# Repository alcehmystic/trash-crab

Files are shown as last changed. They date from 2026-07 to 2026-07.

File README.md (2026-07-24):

<p align="center">
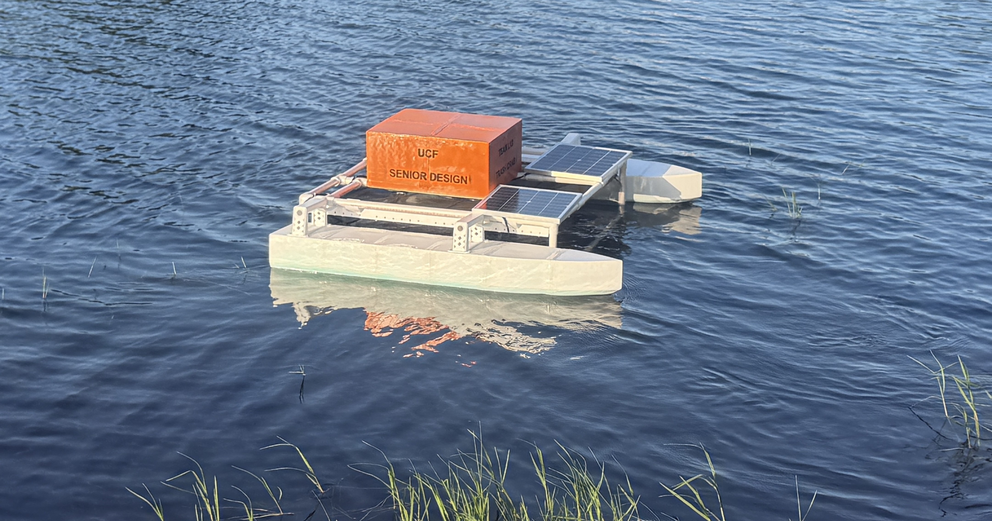
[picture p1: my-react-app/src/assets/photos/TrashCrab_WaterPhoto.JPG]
Trash Crab Team with Trash Crab Robot
  
</p>

<h1 align="center">The Trash Crab</h1>

<p align="center">
  An open-source, low-cost, tele-operated surface vehicle for collecting floating debris in lakes, ponds, and other calm freshwater bodies.
</p>

## About

Marine debris is a serious problem for wildlife, and there's no real affordable, mobile, wildlife-safe way to actively collect floating trash in small bodies of water. Shore crews can't reach open water, stationary filters only cover a fixed area, and pump-based systems risk harming aquatic life.

Trash Crab is our attempt at an answer: a solar-assisted, remote-controlled catamaran raft with a forward-facing mesh collection basket. An operator deploys the boat, drives it to intercept floating debris, and brings it back to empty the basket and recharge. The whole project (hardware, firmware, dashboard software, and 3D models) is published here so it can be built, used, and improved by others.

This project was built by Group L13 as a Computer Science Senior Design project at the University of Central Florida during the Spring/Summer 2026 semesters.

## Features

- **Remote tele-operation** over a long-range (~30 km) radio link, with WASD driving controls and a hardware-backed emergency stop
- **Live web dashboard** (React + MapLibre) showing GPS position and heading, connection status, and drive telemetry in real time
- **Automatic failsafe**: the boat stops itself if it loses contact with the operator
- **GPS tracking** with live position and heading shown on an interactive map
- **Onboard trash detection** using a fine-tuned YOLOv8n model running on a Luxonis OAK-D Lite stereo camera
- **Fully 3D-printed hull and basket**: STL/3MF files included for anyone who wants to build their own
- Designed around a bill of materials of roughly **$1,000-$1,300**, aiming to keep replication relatively affordable

## How it works

```
          Laptop (operator)                        Raspberry Pi 5 (onboard)
 +----------------------------------+   radio   +---------------------------+
 | React dashboard (Vite)           | <-------> | pi-side_telecom_server.py |
 |         |                        |  (LoRa)   |         |                 |
 |         v                        |           |         v                 |
 | dashboard-side_telecom_server.py |           | Arduino Nano (motors)     |
 |      (Flask)                     |           | VK-162 GPS (USB)          |
 |         |                        |           | OAK-D Lite (CV, planned)  |
 |         v                        |           +---------------------------+
 | COM port / radio dongle          |
 +----------------------------------+
```

- The dashboard sends drive commands (`W`/`A`/`S`/`D`) and an emergency stop to a small Flask server running locally on the operator's laptop, which forwards them over the radio link.
- The Raspberry Pi on the boat receives those commands, converts them into left/right motor speeds, and passes them to an Arduino Nano over serial, which handles the actual motor PWM.
- The Pi also reads GPS fixes from a USB GPS dongle and sends a telemetry packet back over the radio once a second (position, elapsed time, connection status, sensor placeholders).
- If the Pi stops receiving commands for more than a second, it cuts the motors on its own rather than waiting for another STOP command.

## Repository structure

```
trash-crab/
├── my-react-app/                       # Dashboard: React frontend + Flask telecom bridge
│   ├── src/                            # Dashboard UI (controls, live stats, map view)
│   ├── dashboard-side_telecom_server.py
│   └── requirements.txt
├── trash-crab-pi/                      # Code that runs on the Raspberry Pi
│   ├── pi-side_telecom_server.py
│   ├── arduino-motor-controller.ino    # Flashed onto the Arduino Nano
│   ├── startup-crab.service            # systemd unit for launching on boot
│   └── requirements.txt
├── assembly/                           # Build guide and reference photos
│   ├── ASSEMBLY.md
│   └── photos/
└── stl-files/                          # 3D-printable hull, basket, and mount parts
```

## Hardware overview

| Vessel | Catamaran-style raft, ~36" L x 48" W x 20" H, forward mesh collection basket |
|---|---|
| Capacity | ~70 gallon basket volume |
| Speed / Range | 0.5–1 m/s / up to ~30 km on the radio link |
| Runtime | 4–6 hours per charge, extended by onboard solar panels (~12–15 hrs to recharge) |

| Layer | Hardware |
|---|---|
| Main computer | Raspberry Pi 5 (Python, headless) |
| Low-level motor control | Arduino Nano running [`arduino-motor-controller.ino`](trash-crab-pi/arduino-motor-controller.ino) (C++, PWM over serial) |
| Navigation | VK-162 USB GPS module |
| Radio link | LoRa LR900-F data transmit module |
| Vision | Luxonis OAK-D Lite (stereo camera + onboard NPU) |

3D-printable parts for the hulls, collection basket, thruster mounts, and component enclosure are in [`stl-files/`](stl-files/). Step-by-step build instructions with photos are in the [assembly manual](assembly/ASSEMBLY.md).

## Machine learning

Floating debris detection runs on a YOLOv8n model, fine-tuned on the FloW-A dataset (floating waste in inland waterways, ICCV 2021) using the Ultralytics training framework. It reached an mAP@0.5 of 0.873 with an 84% true positive detection rate on validation data, and is small enough to run in real time on the OAK-D Lite's onboard NPU. Obstacle detection and a basket-fullness estimator (OpenCV frame analysis) were designed alongside it; obstacle detection is still waiting on a training dataset before it can ship.

## Getting started

You'll need two things running: the code on the Raspberry Pi (boat side) and the dashboard on your laptop (operator side). They talk to each other over a matched pair of radio modules: one plugged into the Pi, one plugged into the laptop.

### Prerequisites

- Raspberry Pi 5 with Python 3.9+, wired to an Arduino Nano, a VK-162 GPS dongle, and a radio module
- The Arduino Nano flashed with [`arduino-motor-controller.ino`](trash-crab-pi/arduino-motor-controller.ino) (steps below, right from the Pi's terminal)
- A laptop with [Node.js](https://nodejs.org/) 18+ and Python 3.9+, with a matching radio module plugged in
- Both Python environments need their own virtual environment (recommended) and dependencies from the matching `requirements.txt`
- [Git](https://git-scm.com/) 2.25+ on both machines, to clone just the folder each one needs

### 1. Raspberry Pi setup

```bash
mkdir trash-crab && cd trash-crab
git clone --filter=blob:none --sparse https://github.com/alcehmystic/trash-crab.git .
git sparse-checkout set trash-crab-pi
cd trash-crab-pi
python -m venv .venv
source .venv/bin/activate
pip install -r requirements.txt
```

#### Flashing the Arduino Nano

This uses [arduino-cli](https://arduino.github.io/arduino-cli/), so the Nano can be flashed straight from the Pi's terminal with the Nano plugged in over USB, no separate desktop or GUI IDE needed. Install it once, along with the AVR core and the `Servo` library the sketch needs:

```bash
curl -fsSL https://raw.githubusercontent.com/arduino/arduino-cli/master/install.sh | sh
sudo mv bin/arduino-cli /usr/local/bin/
arduino-cli core update-index
arduino-cli core install arduino:avr
arduino-cli lib install Servo
```

Arduino sketches must live in a folder with the same name as the `.ino` file, so copy it into one, then compile and upload:

```bash
mkdir arduino-motor-controller
cp arduino-motor-controller.ino arduino-motor-controller/
arduino-cli compile --fqbn arduino:avr:nano arduino-motor-controller
arduino-cli upload -p /dev/ttyUSB0 --fqbn arduino:avr:nano arduino-motor-controller
```

Run `arduino-cli board list` first if you're not sure which port the Nano shows up as. This only needs to be redone if `arduino-motor-controller.ino` changes.

Before running `pi-side_telecom_server.py`, open it and check the **CONFIGURATION** block near the top of the file. It lists the serial ports for the radio, the Arduino, and the GPS dongle. The defaults match our own Pi, but yours will likely enumerate differently. Run `ls -l /dev/serial/by-id/` on the Pi to find the correct by-id names for your own devices and swap them in.

```bash
python pi-side_telecom_server.py
```

#### Starting automatically on boot

[`startup-crab.service`](trash-crab-pi/startup-crab.service) is a systemd unit that launches `pi-side_telecom_server.py` on boot, so the boat is ready to drive as soon as the Pi powers on, with no monitor, keyboard, or WiFi needed. Edit the `WorkingDirectory` and `ExecStart` paths inside it to match where you cloned the repo on your own Pi, then install it:

```bash
sudo cp startup-crab.service /etc/systemd/system/
sudo systemctl daemon-reload
sudo systemctl enable --now startup-crab.service
```

Check on it with `systemctl status startup-crab.service`, or watch its logs live with `journalctl -u startup-crab.service -f`.

### 2. Dashboard setup

```bash
mkdir trash-crab && cd trash-crab
git clone --filter=blob:none --sparse https://github.com/alcehmystic/trash-crab.git .
git sparse-checkout set my-react-app
cd my-react-app
npm install
python -m venv .venv
source .venv/bin/activate
pip install -r requirements.txt
```

Open `dashboard-side_telecom_server.py` and set `PORT` (near the top of the file) to whatever COM port your radio adapter shows up as (Device Manager on Windows, or `/dev/tty*` on Mac/Linux).

```bash
npm run dev
```

This starts the Vite dev server and the telecom bridge together. The program is ran entirely offline. Open `http://localhost:5173` in a browser to see the dashboard. If you'd rather run them separately, use `npm run dev:frontend` and `npm run dev:telecom` in two terminals.

### Getting the whole repository

The steps above only pull down the one folder each device needs. If you want everything at once instead, including the [`stl-files/`](stl-files/) for 3D printing your own parts, just do a normal full clone:

```bash
git clone https://github.com/alcehmystic/trash-crab.git
cd trash-crab
```

## Bill of materials

Rough parts list and cost for building your own Trash Crab. Prices are estimates and will shift depending on suppliers and substitutions. Some parts are noted with a brand due to components being sized around them.

| Category | Component(s) |
|---|---|
| Compute / Control | Raspberry Pi 5 (8GB) x1, Arduino Nano x1 |
| Sensors & Navigation | VK-162 GPS (w/ or w/o magnetometer) x1, MPU6050 IMU x3, leak sensor x4 |
| Propulsion | 12V brushless underwater thrusters w/ESC x4 (We used DIAMONDDYNAMICS 1.2kg Thrust model) |
| Structure & Hull | PETG filament (~9-10kg, depending on print settings), 3/4" PVC pipe for the frame (40-45 ft, cut to length), PVC fittings (3-piece corner-connectors x8, 3-piece T-connectors x12, 4-piece cross-connectors x4) |
| Waterproofing/Glue | Marine silicone sealant 10oz x2 (for hulls, frame, and box) |
| Power System | 12.8V 100Ah LiFePO4 battery x1 (DEASON), 20W solar panel w/charge hub x2 (SOLPERK), power distribution board x1, 12v to 5v/5A Buck Converter to USB-C x1, wiring and adapters |
| Communications | MicoAir LoRa LR900-F radio data transmit module x1 |
| Connections | 1/2" #10-32 non-countersunk bolts/nuts x16 |

**Estimated total: $900-$1,200**, depending on part pricing and substitutions.

## Team

| Name | Role |
|---|---|
| Benedetto Falin | Hardware Construction / SCRUM Manager |
| Kevin Fernandez | Hardware Construction |
| Robert Botorog | Machine Learning / Computer Vision |
| Kameron Hyles | Machine Learning / Computer Vision |
| Hailey Kristona | Software / GUI |
| Phuong Trinh Le | Software / GUI |

## License

This project is licensed under the [MIT License](LICENSE).

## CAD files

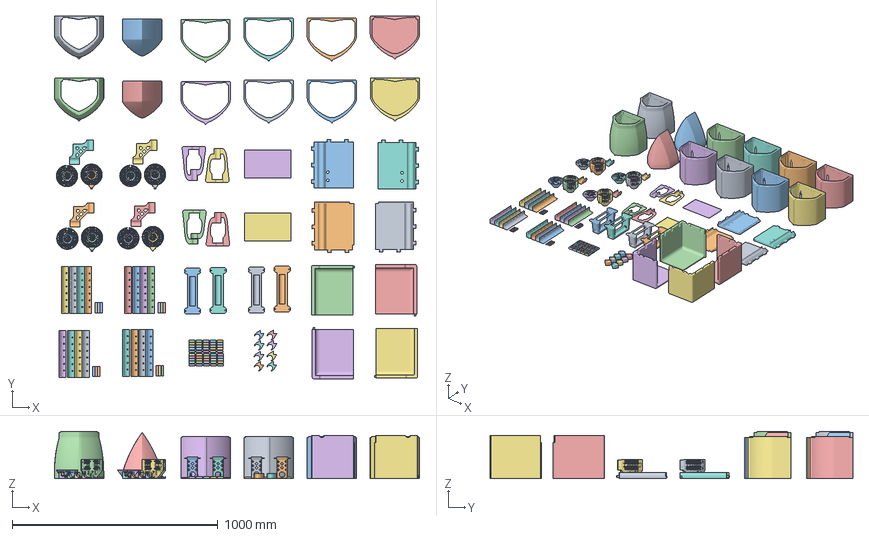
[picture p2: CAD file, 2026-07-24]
stl-files/Catamaran Modules/Catamaran Module - Bow.3mf
1777.6 x 1766.1 x 230.0 mm
Back Bow Body x 2
Front Bow Body x 2
Battery Plate - left
Battery Plate - right
Plate (Left) (1)
Plate (Right)
Plate (Left)
Plate (Right) (1)
Connection Grip x 4
Front Cone x 4
Mid-Body & Back Cone x 4
Clip x 8
Dowel Pin x 12
Length Piece (1) x 4
Length Piece x 12
Cover (1) (1)
Cover (2)
Cover (1)
Cover

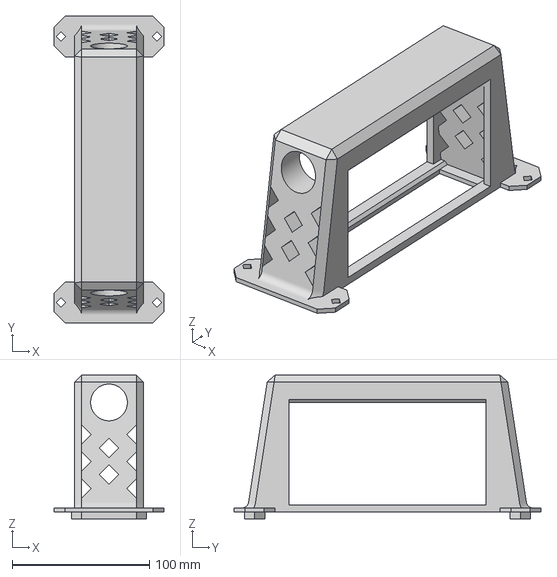
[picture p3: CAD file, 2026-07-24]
stl-files/Handle Grip.3mf
80.0 x 224.0 x 105.0 mm

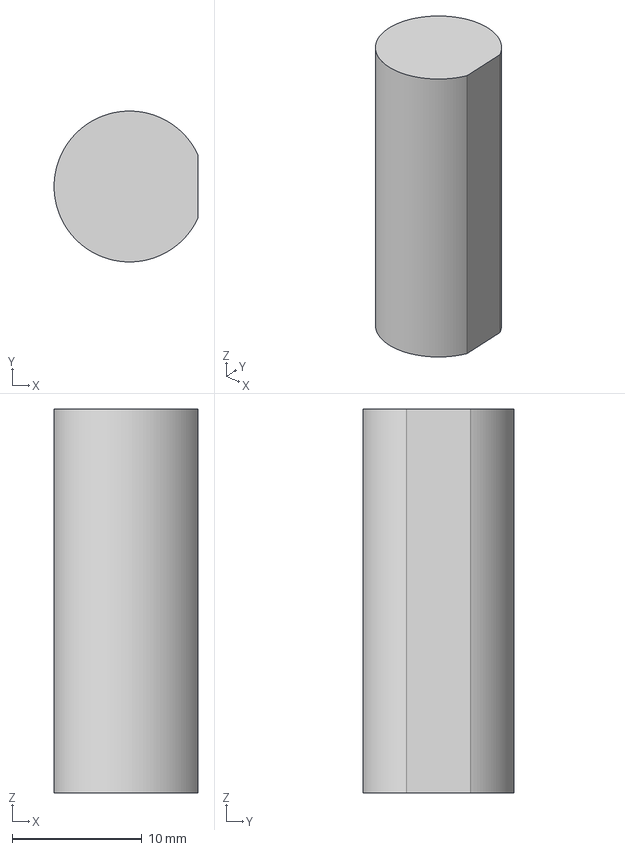
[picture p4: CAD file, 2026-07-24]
stl-files/Catamaran Modules/D-shaft pin.3mf
11.1 x 11.6 x 29.6 mm

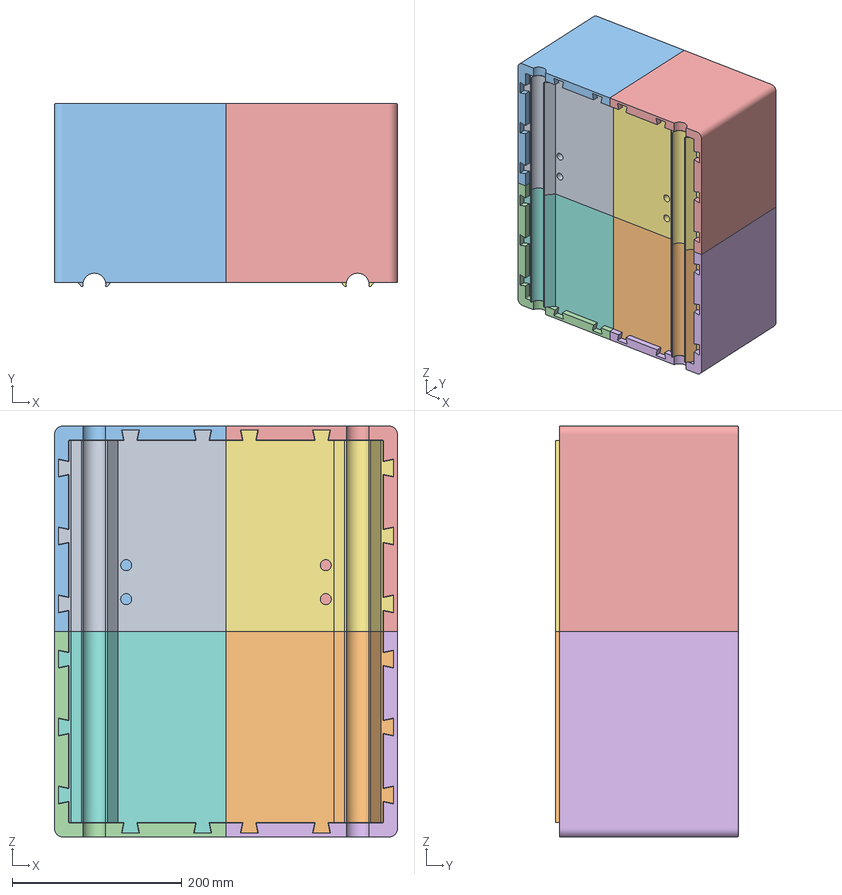
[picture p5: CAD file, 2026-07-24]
stl-files/Components Box & Plate.3mf
404.0 x 215.8 x 484.0 mm
Battery Plate - left
Battery Plate - right
Cover (1) (1)
Cover (1)
Cover (2)
Cover
Plate (Left) (1)
Plate (Left)
Plate (Right) (1)
Plate (Right)

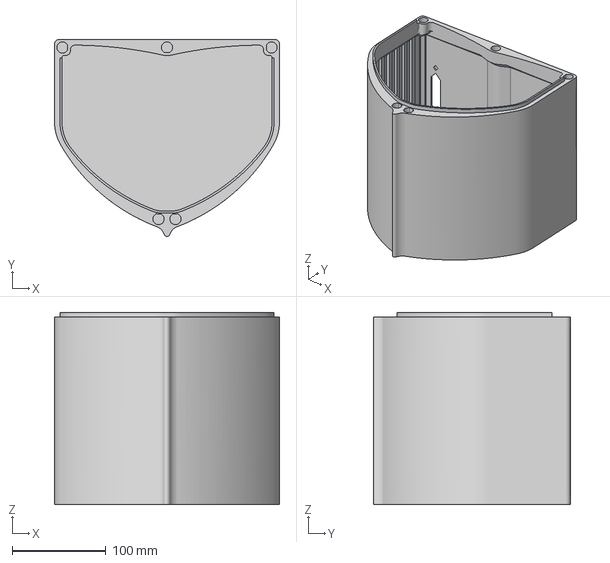
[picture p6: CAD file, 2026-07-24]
stl-files/Catamaran Modules/Catamaran Module - Back.3mf
240.0 x 210.1 x 205.0 mm

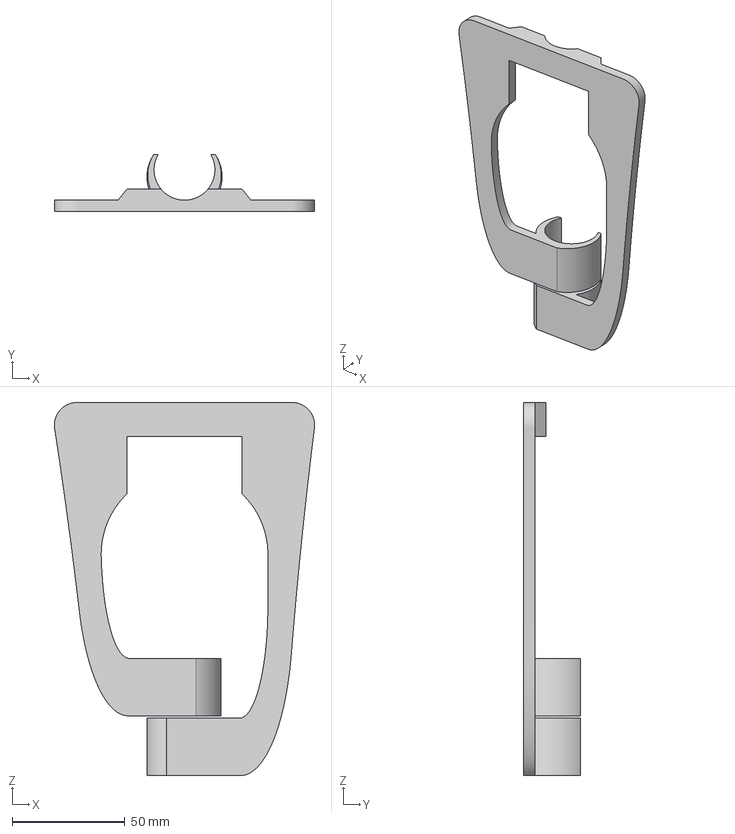
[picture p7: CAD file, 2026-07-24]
stl-files/Hull Grip.3mf
115.2 x 25.2 x 165.1 mm

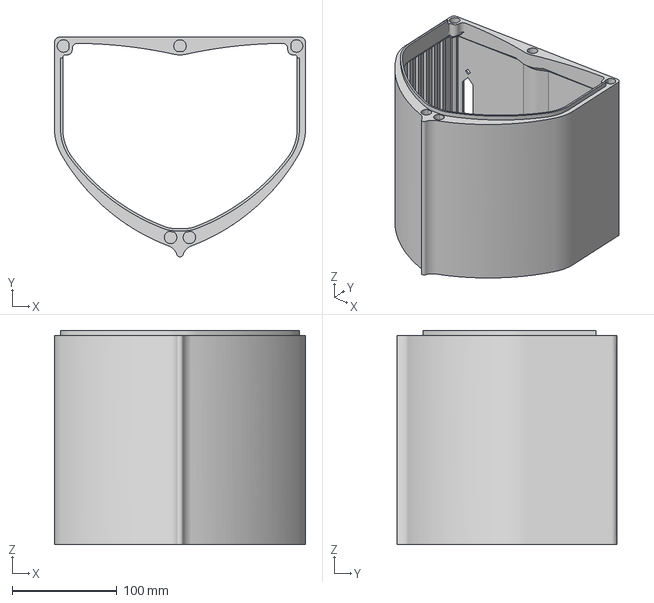
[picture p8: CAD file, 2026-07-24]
stl-files/Catamaran Modules/Catamaran Module - Middle.3mf
240.0 x 210.1 x 205.0 mm

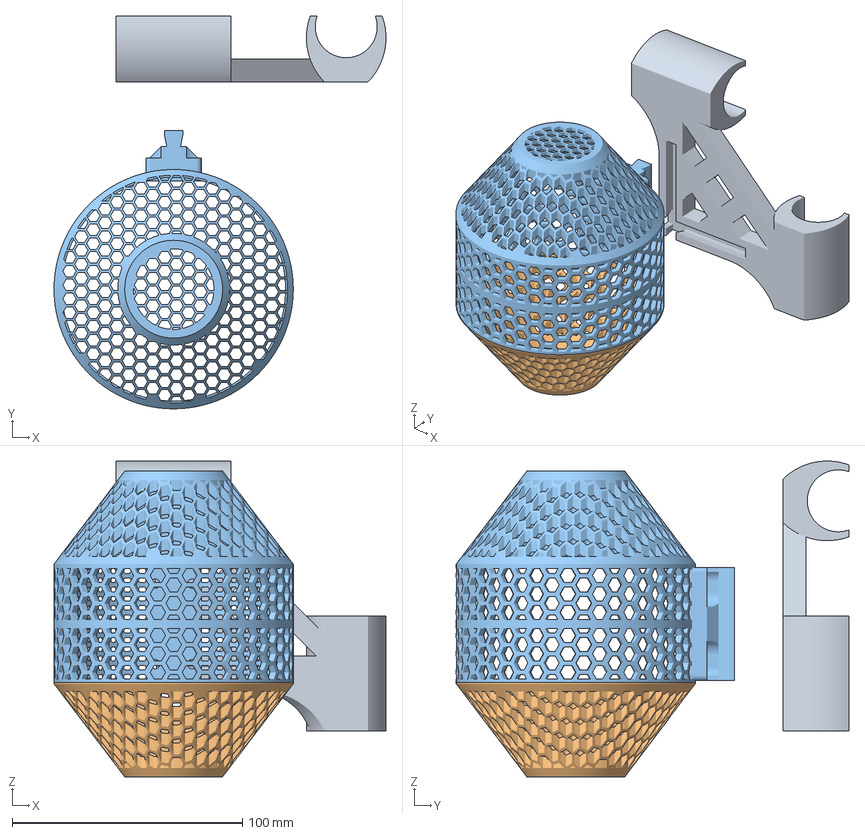
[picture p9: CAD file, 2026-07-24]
stl-files/Thuster Guard & Mount.3mf
144.3 x 170.6 x 137.3 mm
Connection Grip
Front Cone
Mid-Body & Back Cone

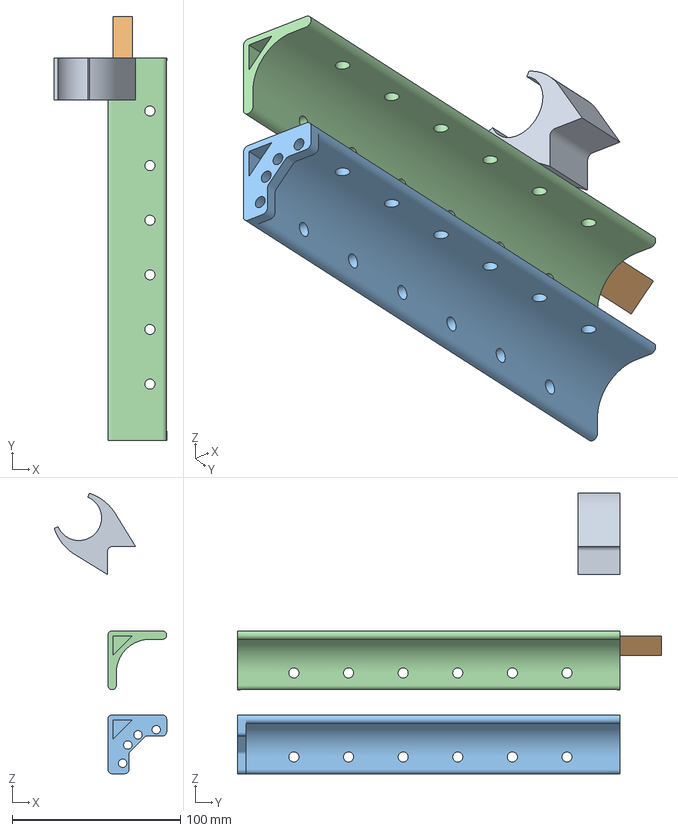
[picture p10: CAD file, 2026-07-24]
stl-files/Basket Structure.3mf
66.9 x 252.3 x 166.9 mm
Clip
Dowel Pin
Length Piece (1)
Length Piece

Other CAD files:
stl-files/Trash Crab 3D Printed Parts 3MF.3mf

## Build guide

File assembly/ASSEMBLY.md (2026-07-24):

# Trash Crab Assembly Manual

This is the build guide for the Trash Crab's hull, frame, basket, and components box. It covers physical assembly only. For flashing the Arduino and running the software, see the [main README](../README.md).

Before starting, print all the parts listed in [`stl-files/`](../stl-files/) and gather the materials in the [Bill of materials](../README.md#bill-of-materials).

The build goes in six stages, roughly in the order you'll actually want to do them:

1. [Assemble the hulls](#1-assemble-the-hulls)
2. [Cut and assemble the PVC frame](#2-cut-and-assemble-the-pvc-frame)
3. [Mount the hulls to the frame](#3-mount-the-hulls-to-the-frame)
4. [Build and mount the basket rails](#4-build-and-mount-the-basket-rails)
5. [Cut and fold the basket netting](#5-cut-and-fold-the-basket-netting)
6. [Assemble the components box and finish](#6-assemble-the-components-box-and-finish)

## 1. Assemble the hulls

Each hull is printed as six segments (bow, four middle modules, stern) that key together with alignment pins before being joined permanently. You'll build two identical hulls.

Lay the six segments out in order and dry-fit them so the alignment pins line up before committing to glue or sealant.

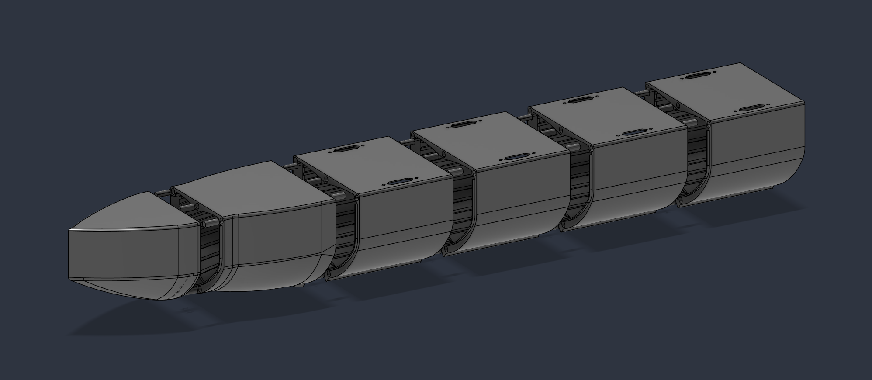
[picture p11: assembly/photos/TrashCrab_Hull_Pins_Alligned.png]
Hull segments laid out in order, pins aligned


Each hull gets two carry grips, attached via four 1/2" #10x32 non-countersunk bolts. These should be hand tightened and not overdone. These must be added before gluing, as there is no way to access the nut after the hulls are sealed.

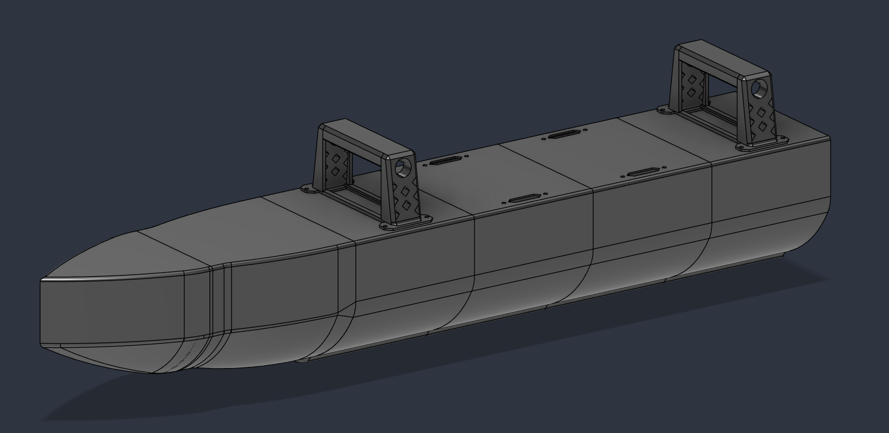
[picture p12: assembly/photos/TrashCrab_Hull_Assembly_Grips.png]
Completed hull with both grips mounted


Apply marine silicone adhesive sealant to each seam, as well as a small dollop on the dowel-pin's hole, and join the segments end to end. This is best done by stacking the hull pieces vertically, with the back catamaran module on the floor, pressing down firmly so sealant seeps out along the edges. Apply a ream of silicone sealant along this outer seam and smooth with a brush or finger (gloved) to create a cleaner seal.

The extra top holes for additional/optional handles can be sealed as well if they are not desired.

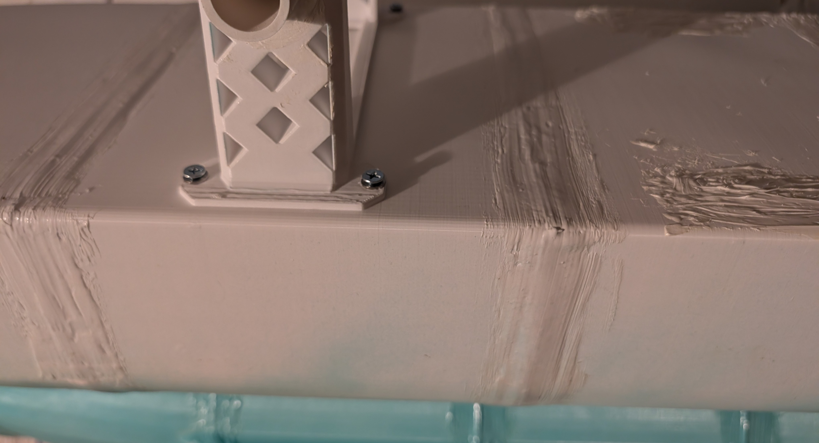
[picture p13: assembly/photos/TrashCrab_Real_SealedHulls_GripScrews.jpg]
Sealed hulls with grip screws installed


Repeat this whole stage for the second hull.

## 2. Cut and assemble the PVC frame

The frame is made from 3/4" Schedule 40 PVC, cut to the lengths below and joined with standard PVC 3-piece corner and T connectors.

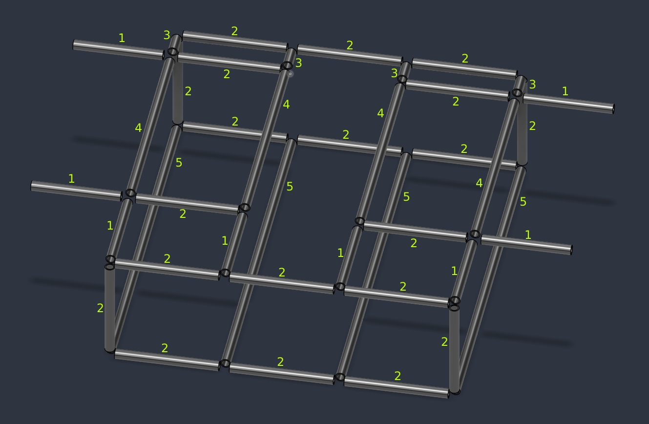
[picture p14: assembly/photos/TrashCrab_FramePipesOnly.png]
PVC frame with each pipe length numbered


Cut list (numbers correspond to the labels above; double check against the diagram before cutting):

| Length | Count | Label |
|---|---|---|
| 9.5" | x8 | (1) |
| 11" | x20 | (2) |
| 2.25" | x4 | (3) |
| 22" | x4 | (4) |
| 37" | x4 | (5) |

**Total: ~45 ft of pipe in total.**

Dry-fit the whole frame with the 3-piece corner and T connectors before gluing anything, to confirm square and fit. We used the same marine silicone adhesive sealant to glue the frame, but any water-safe and flexible PVC glue should work fine.

## 3. Mount the hulls to the frame

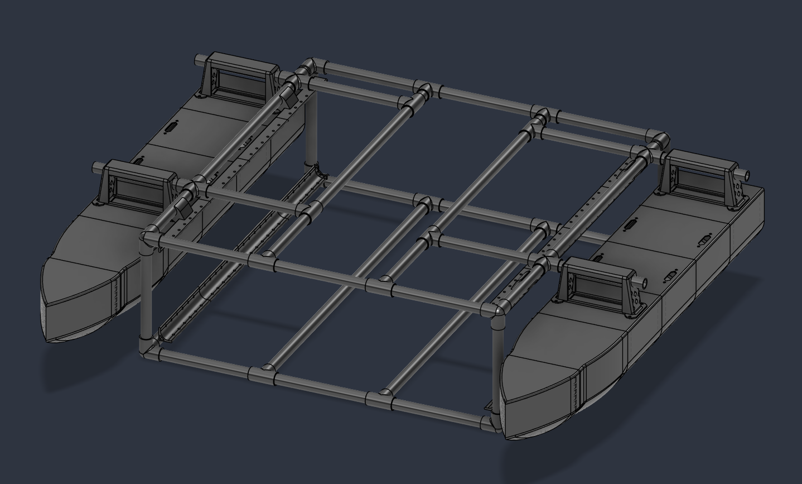
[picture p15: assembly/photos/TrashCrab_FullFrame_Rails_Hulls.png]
Full frame with both hulls and basket rails attached


Each hull gets two of the 9.5" PVC pieces from the frame through the handle grips. This will be a tight fit depending on your printer's tolerances, so be careful not to crack the handles. The pipes should stick out (in the direction of the hull's mounting side) no less than 1" from the handle. Any less, and it risks not fully seating into the frame's cross connection. Aim for 1" - 1.5" so the hull can rest against the frame without sagging. Mirror this direction on the opposite hull as seen above.

Once tested for proper fitting, some glue can be used to lock the PVC pipe to the hull handle grip. Do not seal the PVC pipe to the frame connection, unless you do not want them to be removable.

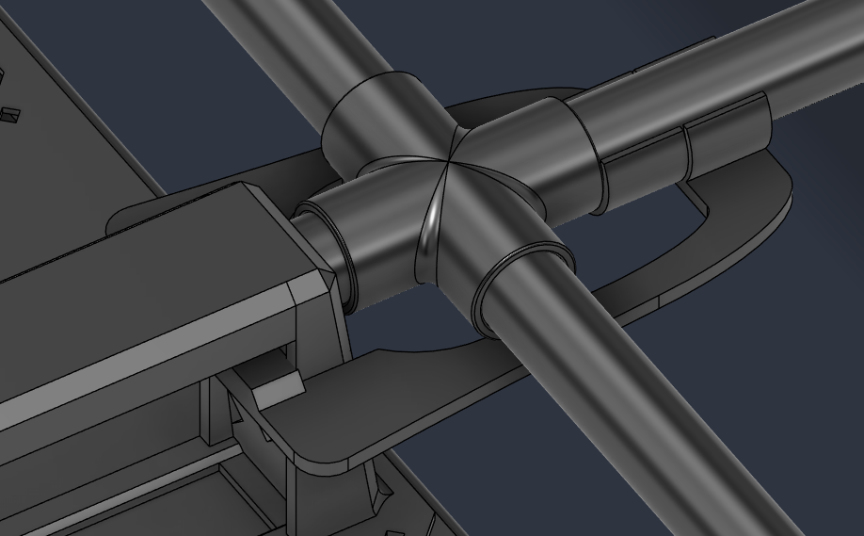
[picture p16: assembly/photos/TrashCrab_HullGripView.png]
Close-up of a hull grip attachment point


Each hull also gets one hull grip clamp. These are bent and placed around the inside of the handle grips, clipping onto the inside PVC frame to ensure the hulls do not slip out of their connection during usage. Before any significant stress is placed on the hulls, the hull grip clamps should be placed and verified for strength.

## 4. Build and mount the basket rails

The basket rails run along the inside of the frame and hold the netting via zip-ties through the provided holes.

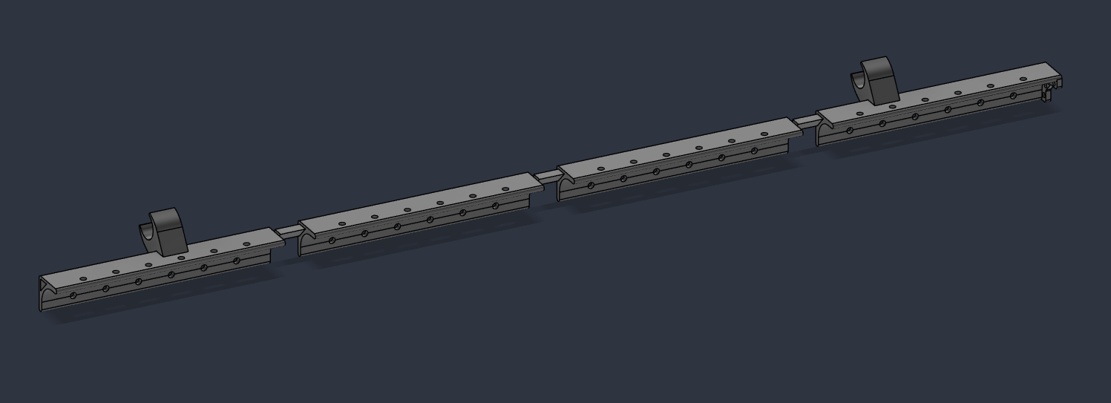
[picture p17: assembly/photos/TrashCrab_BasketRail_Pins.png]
Basket rail segments joined end to end with pin connectors


Join the four rail segments with the triangle-pin connectors with a ream of the marine silicone adhesive sealant on their joining faces to ensure they do not come apart. Note the C-clip hook at each end, used later to hold the netting.

Rail clip hole spacing

Line the C-clips up to be 5" (127mm used as rough guide) from either end of the rail. Apply a ream of the marine silicone adhesive sealant on the inside of each joining face of the C-clip. Press together firmly and let dry.

## 5. Cut and fold the basket netting

We made our basket from garden/plant-safe netting, cut from a flat pattern and folded into shape. Other materials can be used, but remember this will be mainly used for trash collection with constant water flow.

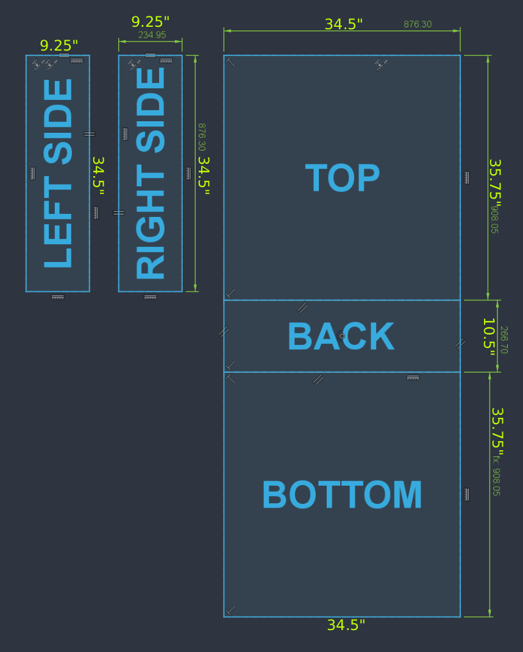
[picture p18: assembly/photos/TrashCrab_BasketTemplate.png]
Flat cutting template: top, back, left side, right side, bottom


Cut the netting to this pattern with the given dimensions in the image above. The dimensions are also listed below:

| Face | Length (vertical) | Width (horizontal) |
|---|---|---|
| Top/Bottom | 35.75" | 34.5" |
| Back | 10.5" | 34.5" |
| Left/Right Side | 34.5" | 9.25" |

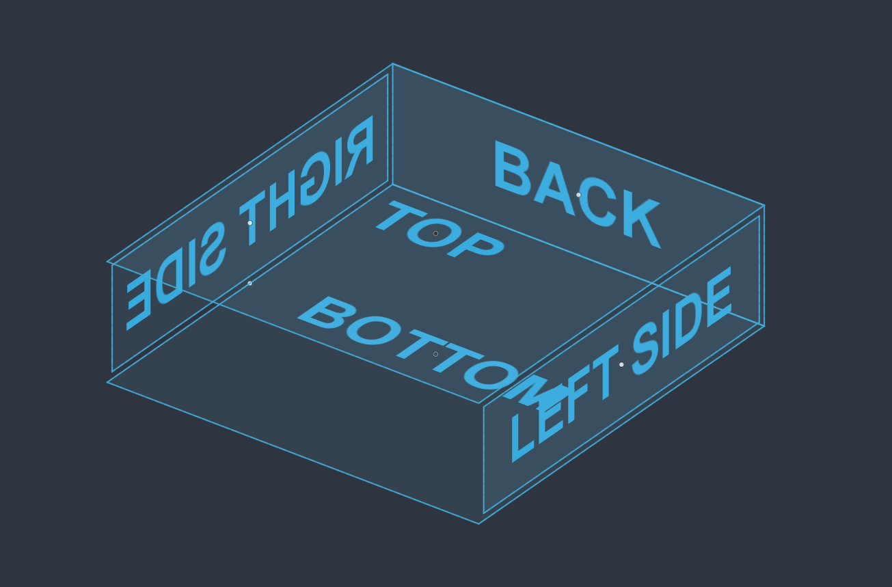
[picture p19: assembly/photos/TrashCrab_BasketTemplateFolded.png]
Template folded into the basket shape


Fold along the seams shown above into the basket shape. The sides are not attached via the folds and are solely zip-tied to the rails.

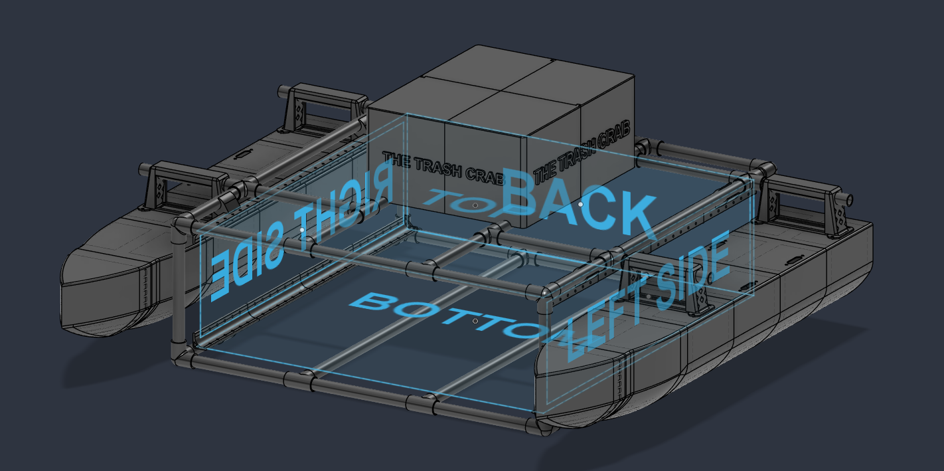
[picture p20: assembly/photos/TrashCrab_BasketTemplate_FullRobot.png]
Basket shown in place on the frame


Attach the folded basket to the rail clips with zip-ties, positioned as shown.

## 6. Assemble the components box and finish

The components box holds the electronics and splits into a lid and base.

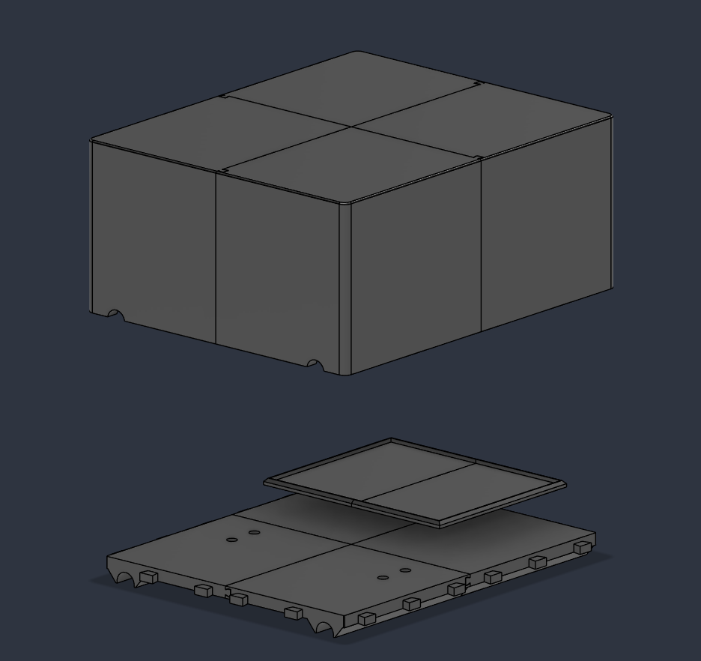
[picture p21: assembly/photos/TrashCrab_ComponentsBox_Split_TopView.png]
Components box, lid and base split, top view


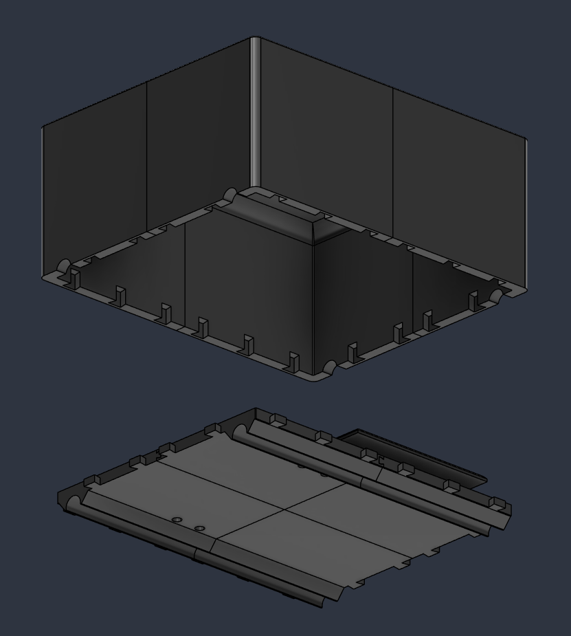
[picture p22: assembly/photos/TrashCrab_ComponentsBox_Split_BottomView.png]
Components box, lid and base split, bottom view


The plates and lid pieces each connect into their respective components via dovetail notches. Each female-side dovetail notch should be lined with some marine silicone adhesive sealant before attaching the pieces.

The plate starts as four pieces which attach in pairs of two, along the short-side dovetail notch to create the left/right sides. These then attach together along the long-side dovetail notch. 

The lid attaches in a spiral fashion with each dovetail notch locking the sides together.

Once all pieces of each component are sealed together, it is recommended to add a ream along the outer seams, similar to what was done when initially sealing the hulls, to ensure a strong connection.

Wire up the electronics inside the base before closing the lid. It slots right onto the plate and sinks down onto it via the dovetail slots on its outer edge. See the main README for the Pi/Arduino/GPS wiring.

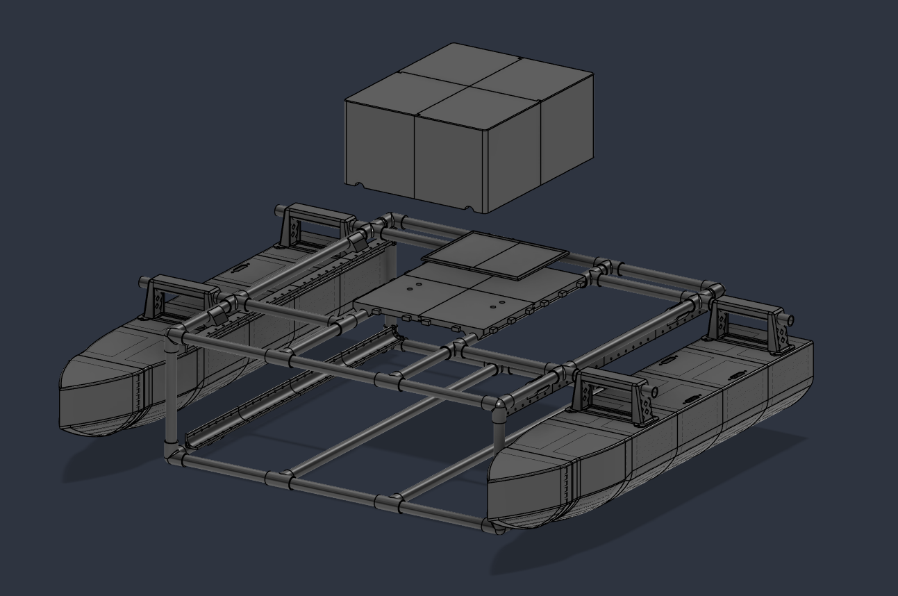
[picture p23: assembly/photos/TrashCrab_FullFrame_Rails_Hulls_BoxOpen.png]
Frame with hulls and rails, box lifted off to show mounting


Mount the box to the frame at the back-middle of the bot with the main battery plate closest to the center for weight distribution. The plate attaches onto the inner PVC pipes running down the center of the top portion of the frame via its C-clips along its bottom.

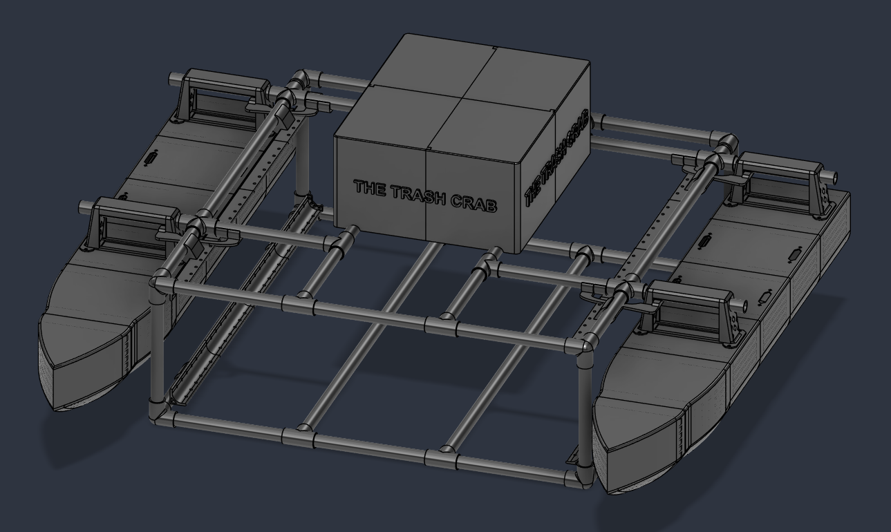
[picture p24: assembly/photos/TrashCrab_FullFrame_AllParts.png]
Fully assembled Trash Crab with box closed


With the box closed, the build is complete. Continue with the [Getting started](../README.md#getting-started) section of the main README to flash the Arduino and bring the electronics online.

Congrats on creating your very own Trash Crab, and thank you for the faith you have placed in this guide as you do so.

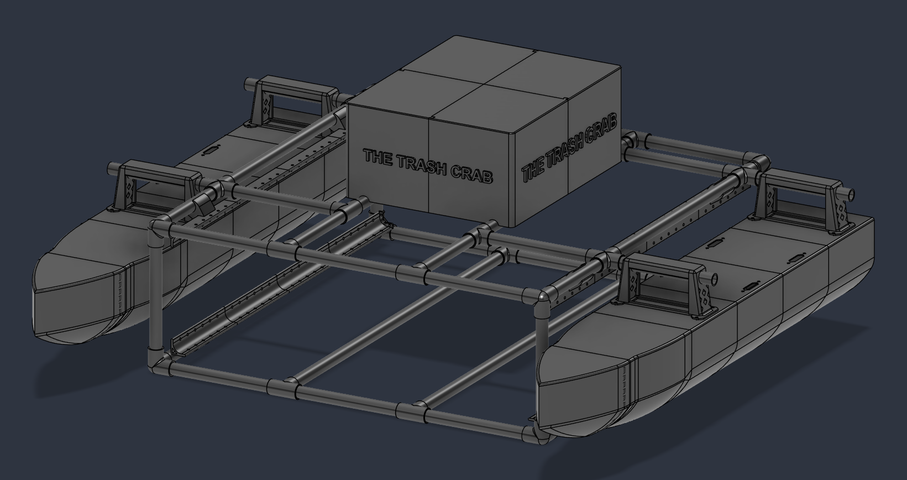
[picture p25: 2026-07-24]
assembly/photos/TrashCrab_FullFrame_Rails_Hulls_BoxClosed.png

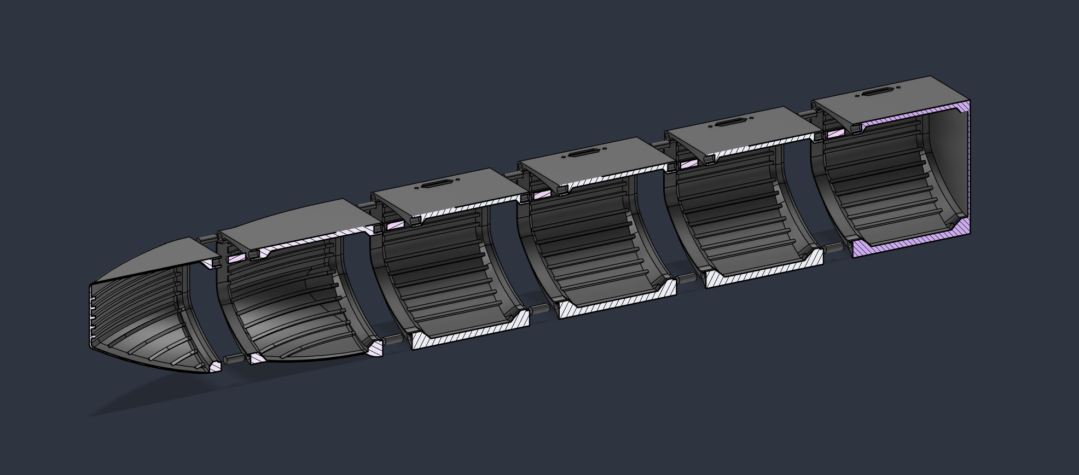
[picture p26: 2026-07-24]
assembly/photos/TrashCrab_Hull_Pins_Alligned_Cut.png

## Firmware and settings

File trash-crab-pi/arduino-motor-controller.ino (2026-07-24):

/*
  arduino-motor-controller.ino

  Runs on the Arduino Nano, connected to the Raspberry Pi over USB serial.
  Owns all real-time motor control: PWM generation, ESC arming, and smooth
  speed ramping. The Pi only sends high-level target speeds; this sketch
  is responsible for actually reaching them safely.

  Motor layout (tank/differential drive, 2 pairs):
    LEFT  pair = PIN_LEFT_FRONT, PIN_LEFT_REAR
    RIGHT pair = PIN_RIGHT_FRONT, PIN_RIGHT_REAR

  Serial protocol (from the Pi, one command per line, newline terminated):
    ARM              -> re-run the ESC arming sequence (neutral hold)
    STOP             -> immediate hard cut to neutral, bypasses the ramp
    T:<left>,<right> -> set target speed for each side, -100..100 (percent)

  PWM convention (ESC standard, in microseconds):
    1500us = neutral / stopped
    2000us = full forward
    1000us = full reverse
  MAX_SPEED_PCT caps how far from neutral we will ever command, no matter
  what target is requested.
*/

#include <Servo.h>

// =====================================================================
// CONFIGURATION - update the pin numbers below if your ESCs are wired
// to different pins. Defaults shown are what our Trash Crab unit uses.
// =====================================================================
const uint8_t PIN_LEFT_FRONT  = 3;
const uint8_t PIN_LEFT_REAR   = 5;
const uint8_t PIN_RIGHT_FRONT = 6;
const uint8_t PIN_RIGHT_REAR  = 9;

const int PULSE_NEUTRAL      = 1500;
const int PULSE_FORWARD_MAX  = 2000;
const int PULSE_REVERSE_MAX  = 1000;
const float MAX_SPEED_PCT    = 85.0;   // hard safety cap, mirrors the Pi-side cap
const unsigned long RAMP_MS  = 1500;   // time to sweep the full -100..100 range

Servo escLF, escLR, escRF, escRR;

// Current and target speeds, in percent (-100..100, later clamped to MAX_SPEED_PCT).
float currentLeft = 0, currentRight = 0;
float targetLeft  = 0, targetRight = 0;
unsigned long lastUpdate = 0;

String inputBuffer = "";

// Converts a -100..100 percent value into a microsecond pulse and writes it.
void writeMotor(Servo &esc, float percent) {
  percent = constrain(percent, -MAX_SPEED_PCT, MAX_SPEED_PCT);
  int pulse;
  if (percent >= 0) {
    pulse = PULSE_NEUTRAL + (percent / 100.0) * (PULSE_FORWARD_MAX - PULSE_NEUTRAL);
  } else {
    pulse = PULSE_NEUTRAL + (percent / 100.0) * (PULSE_NEUTRAL - PULSE_REVERSE_MAX);
  }
  esc.writeMicroseconds(pulse);
}

// ESCs need a neutral signal held for a few seconds before they'll accept
// throttle commands. Runs at boot and again any time "ARM" is received.
void armEscs() {
  Serial.println("Arming ESCs (neutral hold)...");
  escLF.writeMicroseconds(PULSE_NEUTRAL);
  escLR.writeMicroseconds(PULSE_NEUTRAL);
  escRF.writeMicroseconds(PULSE_NEUTRAL);
  escRR.writeMicroseconds(PULSE_NEUTRAL);
  delay(3000);
  currentLeft = currentRight = 0;
  targetLeft  = targetRight  = 0;
  Serial.println("Armed.");
}

void setup() {
  Serial.begin(57600);
  escLF.attach(PIN_LEFT_FRONT);
  escLR.attach(PIN_LEFT_REAR);
  escRF.attach(PIN_RIGHT_FRONT);
  escRR.attach(PIN_RIGHT_REAR);

  armEscs();
  lastUpdate = millis();
}

// Moves currentLeft/currentRight toward their targets at a fixed rate, so a
// full -85..85 sweep takes about RAMP_MS. Non-blocking, called every loop() tick.
void applyRamp() {
  unsigned long now = millis();
  unsigned long dt = now - lastUpdate;
  lastUpdate = now;

  float maxStep = (2.0 * MAX_SPEED_PCT) * (float)dt / (float)RAMP_MS;

  if (currentLeft < targetLeft)       currentLeft = min(currentLeft + maxStep, targetLeft);
  else if (currentLeft > targetLeft)  currentLeft = max(currentLeft - maxStep, targetLeft);

  if (currentRight < targetRight)      currentRight = min(currentRight + maxStep, targetRight);
  else if (currentRight > targetRight) currentRight = max(currentRight - maxStep, targetRight);

  writeMotor(escLF, currentLeft);
  writeMotor(escLR, currentLeft);
  writeMotor(escRF, currentRight);
  writeMotor(escRR, currentRight);
}

void handleCommand(String cmd) {
  cmd.trim();
  if (cmd.length() == 0) return;

  if (cmd == "STOP") {
    // Emergency stop: cut immediately, do not ramp down.
    targetLeft = 0;
    targetRight = 0;
    currentLeft = 0;
    currentRight = 0;
  } else if (cmd == "ARM") {
    armEscs();
  } else if (cmd.startsWith("T:")) {
    int commaIdx = cmd.indexOf(',');
    if (commaIdx > 2) {
      float l = cmd.substring(2, commaIdx).toFloat();
      float r = cmd.substring(commaIdx + 1).toFloat();
      targetLeft  = constrain(l, -MAX_SPEED_PCT, MAX_SPEED_PCT);
      targetRight = constrain(r, -MAX_SPEED_PCT, MAX_SPEED_PCT);
    }
  }
}

// Called automatically by the Arduino core after each loop() pass whenever
// serial data is available. Standard on the Uno/Nano.
void serialEvent() {
  while (Serial.available()) {
    char c = Serial.read();
    if (c == '\n') {
      handleCommand(inputBuffer);
      inputBuffer = "";
    } else if (c != '\r') {
      inputBuffer += c;
    }
  }
}

void loop() {
  applyRamp();
  delay(20); // ~50Hz control loop
}

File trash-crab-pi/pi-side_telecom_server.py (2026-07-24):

"""
pi-side_telecom_server.py

Runs on the Raspberry Pi. This is the bridge between the long-range radio
link (to the dashboard laptop), the Arduino Nano motor controller (over
USB serial), and the VK-162 USB GPS dongle.

What it does:
  - Reads WASD control packets sent from the laptop over radio
  - Converts them into left/right motor speeds and forwards them to the
    Arduino as "T:<left>,<right>"
  - Runs a failsafe watchdog that stops the boat if no control packet
    arrives in time (radio dropout, laptop crash, etc.)
  - Reads NMEA sentences from the GPS dongle and includes the latest fix
    in telemetry
  - Sends a telemetry packet back to the laptop once a second

DEBUG MODE:
  If the Arduino can't be opened on ARDUINO_PORT, the script doesn't crash -
  it just prints what it would have sent instead of writing to serial. Set
  FORCE_DEBUG_MODE = True below to force this even with the Arduino plugged
  in (useful for testing control logic before the hardware is wired up).

Radio protocol from the laptop (newline terminated):
  "ARM"          -> arm the ESCs
  "STOP"         -> emergency stop
  "CTRL:<keys>"  -> currently held keys, e.g. "CTRL:wa" for forward+left

Radio messages sent back to the laptop (newline terminated):
  {"type":"telemetry", ...}  -> once per second
  "Pi: ..."                  -> plain-text ACKs for ARM/STOP/CTRL

GPS setup:
  Needs pynmea2 to parse NMEA sentences: pip install pynmea2
  If it's not installed, or the dongle isn't plugged in, the GPS thread
  just logs that once and disables itself - everything else keeps running.
"""

import serial
import sys
import threading
import time
import json

# Running under systemd buffers stdout in full blocks instead of by line,
# so prints don't show up in `journalctl` until the buffer fills. Force
# line buffering so log output shows up right away.
try:
    sys.stdout.reconfigure(line_buffering=True)
    sys.stderr.reconfigure(line_buffering=True)
except Exception:
    pass

# =====================================================================
# CONFIGURATION - update the port values below to match your own setup.
# Defaults shown are what our Trash Crab unit uses.
# =====================================================================

# Long-range radio link to the laptop dashboard.
RADIO_PORT = "/dev/serial/by-id/usb-Silicon_Labs_CP2102_USB_to_UART_Bridge_Controller_0001-if00-port0"
RADIO_BAUD = 57600

# USB serial link to the Arduino Nano motor controller.
ARDUINO_PORT = "/dev/serial/by-id/usb-1a86_USB_Serial-if00-port0"
ARDUINO_BAUD = 57600

# VK-162 USB GPS dongle.
GPS_PORT = "/dev/serial/by-id/usb-u-blox_AG_-_www.u-blox.com_u-blox_7_-_GPS_GNSS_Receiver-if00"
GPS_BAUD = 9600

# With three USB-serial devices plugged into the Pi at once, /dev/ttyUSB0 or /dev/ttyACM0 style names
# can swap around on every reboot depending on enumeration order. Run `ls -l /dev/serial/by-id/` on 
# your own Pi and copy the matching by-id name into the three PORT values above. These stay stable across reboots.

GPS_ENABLED = True                # master on/off switch for the GPS feed
GPS_RETRY_DELAY = 3.0              # seconds between GPS reconnect attempts
GPS_STALE_TIMEOUT = 5.0            # a fix older than this is reported as lost

MAX_SPEED_PCT = 85                 # global speed cap, mirrors the Arduino-side cap
FAILSAFE_TIMEOUT = 1.0             # seconds without a control packet before auto-stop
FORCE_DEBUG_MODE = False           # True = always print instead of writing to the Arduino

ARDUINO_CONNECT_RETRIES = 5        # startup connection attempts before falling back to debug mode
ARDUINO_CONNECT_RETRY_DELAY = 2    # seconds between those attempts

# PWM constants mirrored from arduino-motor-controller.ino. Used only to
# preview what pulse width the Arduino would generate, for the debug-mode printout.
PULSE_NEUTRAL = 1500
PULSE_FORWARD_MAX = 2000
PULSE_REVERSE_MAX = 1000
RAMP_MS = 1500                     # ramp time mirrored from arduino-motor-controller.ino

GPS_DIAG_LOG_INTERVAL = 5.0        # seconds between GPS diagnostic log lines

# pynmea2 is only needed for GPS parsing, so import it defensively.
# A missing dependency shouldn't take down the rest of the bridge.
GPS_LIB_AVAILABLE = False
if GPS_ENABLED:
    try:
        import pynmea2
        GPS_LIB_AVAILABLE = True
        print("[GPS] pynmea2 imported OK.")
    except Exception as e:
        print(f"[GPS] pynmea2 unavailable ({type(e).__name__}: {e}); "
              "GPS feed disabled, everything else runs normally.")

# Timestamp the script started, so elapsed time in telemetry is measured
# from here and not from the first ARM/control packet.
SCRIPT_START_TIME = time.time()


def open_radio():
    """Open the radio serial port, retrying forever until it connects.
    Used both at startup and to reconnect after a dropped link."""
    while True:
        try:
            # write_timeout keeps a stuck/backed-up write from hanging
            # forever and freezing telemetry along with it.
            ser = serial.Serial(RADIO_PORT, RADIO_BAUD, timeout=1, write_timeout=5)
            print(f"Radio connected on {RADIO_PORT}")
            return ser
        except (serial.SerialException, FileNotFoundError) as e:
            print(f"[RADIO] Could not open {RADIO_PORT} ({e}). Retrying in 2s...")
            time.sleep(2)


radio = open_radio()

# Guards every read/write on `radio`. The radio link is half-duplex, so
# without this lock the telemetry thread and the main control loop could
# collide mid-write.
radio_lock = threading.Lock()

arduino = None
ARDUINO_CONNECTED = False
if not FORCE_DEBUG_MODE:
    for attempt in range(1, ARDUINO_CONNECT_RETRIES + 1):
        try:
            arduino = serial.Serial(ARDUINO_PORT, ARDUINO_BAUD, timeout=1)
            time.sleep(2)  # give the Arduino time to reset after the port opens
            ARDUINO_CONNECTED = True
            print(f"Arduino connected on {ARDUINO_PORT}")
            break
        except (serial.SerialException, FileNotFoundError) as e:
            print(f"[ARDUINO] Attempt {attempt}/{ARDUINO_CONNECT_RETRIES}: "
                  f"could not open {ARDUINO_PORT} ({e}).")
            if attempt < ARDUINO_CONNECT_RETRIES:
                time.sleep(ARDUINO_CONNECT_RETRY_DELAY)

if not ARDUINO_CONNECTED:
    print("[DEBUG MODE] Running without Arduino. Commands will be printed, not sent.")
    print("[DEBUG MODE] Set FORCE_DEBUG_MODE = False and connect the Nano to go live.\n")

last_ctrl_time = time.time()
lock = threading.Lock()
failsafe_active = False  # only used so the failsafe trip message prints once, not every loop

# --- Debug-mode ramp preview state (mirrors currentLeft/Right, targetLeft/Right in the .ino) ---
sim_current_left = 0.0
sim_current_right = 0.0
sim_target_left = 0.0
sim_target_right = 0.0
sim_lock = threading.Lock()
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

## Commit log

2026-02-20 Added buttons and info boxes to controls widget
2026-02-21 Completed Live Stats widget and added some button hovering effects for controls
2026-02-25 added logo and added status button
2026-03-07 added status buttons and the settings logo
2026-06-29 added buttons!
2026-06-30 Button reponses
2026-06-30 Changed sendCommand function for button functionality
2026-07-17 Added GPS and Updated Dashboard Layout
    Added GPS by ID over USB to Pi code. Updated Dashboard layout and removed sensors from telemetry as they are not connected. Endpoints still present without actual data being sent.
2026-07-24 Code consolidation, git organization, and README Setups
    Consolidated and organized code folders and STL files for 3D-Printing. README now properly setup with setup instructions and BOM. Unnecessary code removed for organization sake. Ready to merge to mai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
    [Basket Structure.3mf, Catamaran Module - Back.3mf, Catamaran Module - Bow.3mf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]
2026-07-24 Minor README changes and assembly manual addition
    Minor parts list changes on README and full addition of assembly markdown manual with photos and new folder directory for such.
